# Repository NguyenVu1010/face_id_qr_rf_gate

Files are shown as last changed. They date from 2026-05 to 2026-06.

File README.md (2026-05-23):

# smart_gate (Pi 5 side)

See `docs/superpowers/specs/2026-05-22-pi-app-design.md` for design.

## Dev setup

```
python3 -m venv --system-site-packages .venv
source .venv/bin/activate
pip install -r requirements-dev.txt
pytest tests/ -q
```

## Production install

```
sudo bash scripts/install.sh
```

## Pi GPIO UART setup (one-time, before first run)

The daemon talks to ESP32 over the Pi GPIO UART (`/dev/serial0`), not USB-CDC.
Before first run:

1. Disable Pi serial console:
   ```
   sudo raspi-config
   # Interface Options → Serial Port
   #   "Login shell over serial?" → NO
   #   "Serial port hardware enabled?" → YES
   sudo reboot
   ```
2. Verify the device exists and is readable:
   ```
   ls -l /dev/serial0    # should be a symlink to ttyAMA0 or ttyS0
   ```
3. Wire 3 Dupont leads between Pi GPIO header and ESP32 DevKit:
   - Pi pin **8** (BCM14, TX0) → ESP32 **GPIO 32** (UART1 RX)
   - Pi pin **10** (BCM15, RX0) ← ESP32 **GPIO 25** (UART1 TX)
   - Pi pin **6** (GND) ↔ ESP32 GND

4. Add the daemon user to `dialout` so it can open `/dev/serial0`:
   ```
   sudo usermod -aG dialout smart-gate
   ```

## Flashing ESP32 (must stop daemon)

Firmware flashing still needs a separate USB cable from the Pi to the DevKit
USB-C/micro-USB port. `esptool.py` needs DTR/RTS auto-reset which the GPIO
UART doesn't provide.

```
sudo systemctl stop smart-gate
# Plug USB cable Pi → DevKit (data + power OK while daemon is stopped; the
# servo isn't moving and Pi USB current budget is plenty for the no-load case)
esptool.py --chip esp32 --port /dev/ttyUSB0 --baud 921600 write_flash 0x0 firmware.bin
# Unplug USB cable (or leave it for `pio device monitor` debug log)
sudo systemctl start smart-gate
```

After flashing, runtime traffic resumes over `/dev/serial0` (the GPIO UART).
The USB cable is optional while the daemon runs.

## Web admin smoke test (pre-merge)

With the daemon running and the ESP32 connected:

1. Open `http://<pi>:8080/`. Top bar shows green **LINK** pill + cap fps number + frame-age (< 1s). Stream `<img>` shows a placeholder until the camera publishes.
2. Click **⏵ Open gate** — gate opens, toast "Gate opening…". Click **⏹ Close gate** — toast "Gate closing…".
3. Click **+ Tạo user mới** → confirm dialog → enroll-result card appears with QR thumbnail + ⬇ Tải QR PNG button.
4. Trigger an authorized face match — within 2 s a new row appears at the top of Recent events.
5. Watch the gate badge cycle through `idle → opening → open → timeout_warn → closing → idle` over a 20s arc; `timeout_warn` should pulse.
6. Navigate to `/events`. Toggle the `face` filter pill — only face rows show. Clear filter, choose **denied** — only stranger rows show. Type "ali" in the user search — only alice rows. Pick "Last 7 days" period. Click `▶` on a row that has a clip — native `<dialog>` modal plays the mp4 + offers Download.
7. Navigate to `/users` — alice row visible with QR thumbnail + ⬇ download button. Counter shows "N enrolled".
8. Navigate to `/system` — four status cards green (LINK / CAP / DET / DISK), pretty-printed health JSON, two diag buttons. Click **Send ping** → modal opens with `ack_ms` integer. Click **Send cmd:status** → modal updates with the ESP32-side status payload. ESP32 log scrolls live, newest-first.
9. **Failure-mode walk:**
   - Unplug USB to ESP32. Within ~5 s:
     - Top bar LINK pill turns amber.
     - `link-banner` appears: "⚠ Link down — UART silent. Manual gate commands disabled."
     - `Open gate` → toast "Gate command failed".
     - `#sse-status` becomes "reconnecting…".
   - Replug USB. Within ~5 s: banner disappears, LINK turns green, SSE pill goes live; any ESP32 log lines emitted during the outage are replayed (uses `Last-Event-ID` resume).
10. **Pause / Clear** controls on the ESP32 log list work; capacity is bounded at 500 lines (oldest dropped).

If any step fails: `pytest tests/ -q --ignore=tests/unit/test_cli.py` should still be green; the bug is in templates/JS rather than backend.

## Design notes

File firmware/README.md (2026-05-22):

# smart_gate ESP32 firmware

Implements the firmware described in [`../docs/superpowers/specs/2026-05-22-esp32-firmware-design.md`](../docs/superpowers/specs/2026-05-22-esp32-firmware-design.md).

Talks JSON Lines over USB-CDC to a Raspberry Pi 5. Operates the gate independently of the Pi if the link is lost; RFID auth is local via NVS allowlist.

## Toolchain

- [PlatformIO](https://platformio.org/) (CLI: `pio`).
- Framework: Arduino-ESP32.
- Board: ESP32-WROOM-32 DevKit.

## Pin map (mirrors architecture spec §5)

| GPIO | Peripheral |
| --- | --- |
| 1 | UART0 TX — `pio device monitor` debug + `esptool.py` flashing only |
| 3 | UART0 RX — `pio device monitor` + `esptool.py` flashing only |
| 2 | Onboard status LED |
| 5 | RC522 CS |
| 18  | RC522 SCK |
| 19  | RC522 MISO |
| 23  | RC522 MOSI |
| 17  | RC522 RST |
| 16  | RC522 IRQ (reserved; polling mode) |
| 21  | LCD I2C SDA |
| 22  | LCD I2C SCL |
| **25**  | **UART1 TX → Pi pin 10 (BCM15, RX0)** — Pi app comm |
| **32**  | **UART1 RX ← Pi pin 8  (BCM14, TX0)** — Pi app comm |
| 27  | HC-SR04 TRIG |
| 26  | HC-SR04 ECHO (via voltage divider) |
| 13  | Servo SG90 PWM |
| 14  | Buzzer (via 2N3904 NPN) |

Runtime Pi↔ESP32 app comm uses the **3-wire GPIO UART link** (decision #26, 2026-05-23): ESP32 GPIO 32/25 ↔ Pi header pins 8/10. USB cable to the DevKit is needed only for flashing — unplugged at runtime. The Pi serial console must be disabled in `raspi-config` so `/dev/serial0` is free. LCD I2C pull-up cut required — see architecture spec §5.2.

## Build

```bash
pio run
```

First build downloads platform + libraries (~2–5 min).

## Flash

```bash
# Pi pyserial app must release /dev/ttyUSB0 first.
pio run -t upload
```

Reset is automatic via DTR/RTS on CP2102.

## Monitor

```bash
pio device monitor
```

Press Ctrl+T then Ctrl+H for the picocom-style help.

## UART protocol

See architecture spec §4. JSON Lines, 115200 baud (USB-CDC ignores baud but app config is symmetric with Pi).

Send a `ping`:

```
{"id":1,"type":"cmd","v":"ping"}
```

Expect:

```
{"type":"ack","id":1,"v":"ping","data":{"ok":true}}
```

## Acceptance tests (manual)

| # | Scenario | Expected serial output |
| --- | --- | --- |
| 1 | Power on board | One line `{"type":"evt","v":"boot","data":{"fw":"1.0.0","free_heap":N,"reset_reason":"power_on"}}` within 500 ms |
| 2 | Send `{"id":1,"type":"cmd","v":"ping"}` | `{"type":"ack","id":1,"v":"ping","data":{"ok":true}}` within 100 ms |
| 3 | Scan whitelisted card | `evt:rfid granted` with `name`; `evt:gate opening` → `evt:gate open` after 300 ms; LCD `"Welcome: <name>"`; servo physically opens |
| 4 | Pass hand through HC-SR04 beam | `evt:person_passed` with `distance_cm` and `ms`; `evt:gate closing` → `evt:gate closed` |
| 5 | Scan non-whitelisted card | `evt:rfid denied`; buzzer triple-beep; no gate motion |
| 6 | `cmd:open` then leave alone | `evt:gate opening` → `evt:gate open`; after 10 s `evt:gate timeout_warn` + buzzer warn pattern; after 5 s `evt:gate closing` → `evt:gate closed` |
| 7 | `add_uid` → `list_uids` → reboot → `list_uids` | Second `list_uids` after reboot still contains added UID |
| 8 | `remove_uid` for unknown UID | `ack` with `{"ok":false,"err":"not_found"}` |
| 9 | `cmd:config {"close_timeout_s":3}` then `cmd:open` and idle | Timeout warning fires at 3 s instead of 10 s |
| 10 | Disconnect Pi USB, scan whitelisted card | RFID auth still works end-to-end (boards standalone) |
| 11 | Send malformed JSON | `evt:log warn` with `tag:"uart"`; next valid message still processed |
| 12 | Hold whitelisted card on reader | `evt:rfid granted` fires once; identical events suppressed until card removed |

Record pass/fail in `firmware/test-log.md` (create on first acceptance run).

## Troubleshooting

- **`pio run -t upload` fails with "Resource busy"** — another process holds `/dev/ttyUSB0`. Stop the Pi app or `fuser -k /dev/ttyUSB0`.
- **No serial output at all** — check USB cable (some are charge-only), check `pio device list` for the right port name.
- **LCD shows garbage** — pull-up cut not done (architecture spec §5.2). Cut the on-backpack 4.7 kΩ pull-ups, the carrier PCB pull-ups to 3V3 take over.
- **RFID never reads** — confirm SPI wiring; the RC522 module's onboard regulator drops 3V3 if there's a short.
- **HC-SR04 always reads 0** — confirm voltage divider on ECHO (5 V → 3.3 V). Direct 5 V to GPIO 26 over time damages the input.
- **Servo jitters** — 470 µF cap on 5 V rail not installed (architecture spec §2.2).

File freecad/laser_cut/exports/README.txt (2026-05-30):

MICA GATE PILLAR — LASER CUT SPEC
=================================

Project: Smart gate pillar enclosure (Pi 4 + ESP32 + sensors)
Date:    2026-05-31
File:    mica_gate_pillar.pdf (or .svg)

VẬT LIỆU
--------
Mica acrylic trong suốt, độ dày 5 mm.
Khổ tấm: 1000 × 600 mm (1 tấm đủ).

NÉT CẮT vs NÉT KHẮC
-------------------
- Đường màu ĐỎ (RGB 255,0,0):   CẮT THỦNG
- Đường màu ĐEN (RGB 0,0,0):    KHẮC NÔNG (engrave ~0.2mm)

DANH SÁCH 8 CHI TIẾT
--------------------
1. FRONT     150 × 228 mm  (mặt trước)
2. BACK      150 × 300 mm  (mặt sau, có lỗ adapter Ø10mm)
3. LEFT      240 × 300 mm  (ngũ giác, mặt trái)
4. RIGHT     240 × 300 mm  (ngũ giác, mặt phải, có khe arm 20×130mm + cảm biến; servo dời vào trong)
5. TOP       150 × 168 mm  (mặt trên, có lỗ LCD 98×40 R4)
6. SLOPE     150 × 101.8 mm (mặt vát 45°, có khắc đánh dấu RFID)
7. BOTTOM    150 × 240 mm  (mặt đáy, có 5 khe thông gió)
8. ARM       115 × 15  mm  (cần chắn — có khắc 3 vạch sọc 20mm × 5mm — sau khi cắt sơn ĐỎ vào các vạch khắc để giả barrier sọc đỏ-trắng)

DUNG SAI
--------
±0.2 mm cho lỗ và mép.
Đường cắt cùng tấm phải canh khoảng cách >= 5mm để tránh vỡ mica.

LƯU Ý
-----
- Nét cắt trong file có độ dày 0.3mm (chỉ để hiển thị PDF); máy laser
  cắt theo đường tâm geometry, không theo độ dày stroke.
- Engrave (vùng RFID trên SLOPE và 5 vạch sọc trên ARM) chỉ cần khắc nông, không cắt thủng.

CẢM ƠN!

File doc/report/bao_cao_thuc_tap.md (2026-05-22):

# BÁO CÁO THỰC TẬP TỐT NGHIỆP

**Đề tài:** NGHIÊN CỨU, THIẾT KẾ BỘ ĐIỀU KHIỂN CỔNG THU SOÁT VÉ TỰ ĐỘNG AFC TRONG GIAO THÔNG CÔNG CỘNG

**Sinh viên thực hiện:** [HỌ TÊN SINH VIÊN]
**Mã sinh viên:** [MSV]
**Lớp:** [LỚP]
**Khóa:** [KHÓA]
**Đơn vị thực tập:** [ĐƠN VỊ THỰC TẬP]
**Giáo viên hướng dẫn:** [GVHD]
**Khoa:** Điện – Điện tử
**Trường:** Đại học Giao thông vận tải

Hà Nội, năm 2026

---

# LỜI NÓI ĐẦU

Trong xu hướng phát triển mạnh mẽ của Cách mạng công nghiệp 4.0, các hệ thống thu soát vé tự động (AFC – Automatic Fare Collection) đang trở thành thành phần không thể thiếu của hạ tầng giao thông công cộng hiện đại. Tại Việt Nam, sự ra đời của các tuyến đường sắt đô thị (metro) Hà Nội và TP. Hồ Chí Minh cùng các tuyến xe buýt nhanh (BRT) đặt ra yêu cầu cấp thiết về một thế hệ thiết bị cổng AFC tin cậy, đa dạng phương thức xác thực và có khả năng tích hợp dữ liệu về trung tâm điều hành.

Báo cáo thực tập này trình bày quá trình tìm hiểu, phân tích, thiết kế và xây dựng mô hình *Bộ điều khiển cổng thu soát vé tự động AFC* – một mô hình demo cấp prototype, áp dụng kiến trúc **dual-compute** (hai nút tính toán):

- **Raspberry Pi 5** đảm nhiệm khối thị giác máy tính: thu nhận hình ảnh từ webcam USB, nhận diện khuôn mặt, quét mã QR, lưu trữ cơ sở dữ liệu hành khách – vé và cung cấp giao diện web giám sát.
- **ESP32-WROOM-32** đảm nhiệm khối điều khiển ngoại vi thời gian thực: đọc thẻ RFID 13.56 MHz qua module RC522, điều khiển động cơ Servo SG90 đóng/mở cánh chắn, hiển thị trạng thái lên LCD 20×4, phát âm thanh báo hiệu qua buzzer, phát hiện hành khách đi qua bằng cảm biến siêu âm HC-SR04.

Hai khối tính toán giao tiếp qua **một dây cáp USB duy nhất** sử dụng USB-CDC, vận chuyển bản tin JSON Lines ở tốc độ 115200 baud. Việc tắt Wi-Fi trên ESP32 và loại bỏ MQTT giúp đơn giản hóa hệ thống, giảm bề mặt tấn công và tăng độ tin cậy cho mô hình demo.

Báo cáo trình bày đầy đủ các nội dung từ phân tích yêu cầu, lựa chọn công nghệ, thiết kế phần cứng (KiCad), thiết kế cơ khí (FreeCAD), thiết kế phần mềm (Python + Flask trên Pi, Arduino-ESP32 + FreeRTOS trên ESP32), đến kết quả thử nghiệm và hướng phát triển. Đây là tài liệu tổng kết quá trình thực tập của em tại **[ĐƠN VỊ THỰC TẬP]**, đồng thời là cơ sở để mở rộng đề tài thành đồ án tốt nghiệp.

---

# LỜI CAM KẾT

Em xin cam kết báo cáo thực tập tốt nghiệp với đề tài *“Nghiên cứu, thiết kế bộ điều khiển cổng thu soát vé tự động AFC trong giao thông công cộng”* là công trình nghiên cứu của riêng em dưới sự hướng dẫn của thầy/cô **[GVHD]**. Toàn bộ nội dung phân tích, thiết kế, sơ đồ khối, sơ đồ nguyên lý KiCad, bảng phân chân ESP32, lưu đồ thuật toán và kết quả thử nghiệm trình bày trong báo cáo đều do em thực hiện trong quá trình thực tập tại **[ĐƠN VỊ THỰC TẬP]**. Các tài liệu tham khảo được trích dẫn đầy đủ trong mục Tài liệu tham khảo.

Em xin chịu hoàn toàn trách nhiệm về nội dung báo cáo này.

Hà Nội, ngày ___ tháng ___ năm 2026
Sinh viên thực hiện
**[HỌ TÊN SINH VIÊN]**

---

# LỜI CẢM ƠN

Trong suốt quá trình thực tập tốt nghiệp và hoàn thành báo cáo, em đã nhận được rất nhiều sự giúp đỡ tận tình từ thầy cô, đồng nghiệp và bạn bè.

Trước tiên, em xin gửi lời cảm ơn chân thành đến **Ban Chủ nhiệm Khoa Điện – Điện tử**, Trường Đại học Giao thông vận tải đã tạo điều kiện thuận lợi cho em được tham gia kỳ thực tập tốt nghiệp tại doanh nghiệp.

Em xin trân trọng cảm ơn thầy/cô **[GVHD]** – giáo viên hướng dẫn – đã dành nhiều thời gian quý báu để hướng dẫn em từ khâu lựa chọn đề tài, định hình kiến trúc hệ thống, đến việc rà soát kỹ thuật trong từng phần thiết kế phần cứng và phần mềm. Những góp ý sâu sát của thầy/cô về phân bố chân ESP32, giao thức UART JSON Lines và mô hình tác vụ FreeRTOS đã giúp em tránh được nhiều lỗi tiềm ẩn.

Em cũng xin gửi lời cảm ơn đến **[ĐƠN VỊ THỰC TẬP]** đã tiếp nhận, hướng dẫn và tạo điều kiện cho em được tiếp xúc với môi trường làm việc thực tế, được sử dụng các thiết bị (Raspberry Pi 5, ESP32 DevKit DOIT V1 30-pin, module RC522, LCD I2C, Servo SG90, cảm biến HC-SR04, webcam USB) phục vụ cho việc xây dựng mô hình.

Do thời gian thực tập và năng lực còn hạn chế, báo cáo không tránh khỏi những thiếu sót. Em rất mong nhận được sự góp ý của quý thầy/cô và Hội đồng để báo cáo được hoàn thiện hơn.

Em xin chân thành cảm ơn!

Hà Nội, ngày ___ tháng ___ năm 2026
Sinh viên
**[HỌ TÊN SINH VIÊN]**

---

# MỤC LỤC

**LỜI NÓI ĐẦU** ... i
**LỜI CAM KẾT** ... ii
**LỜI CẢM ƠN** ... iii
**DANH MỤC BẢNG BIỂU** ... iv
**DANH MỤC HÌNH VẼ** ... v
**DANH MỤC CÁC CỤM TỪ VIẾT TẮT** ... vi

**CHƯƠNG 1. TỔNG QUAN VỀ HỆ THỐNG THU SOÁT VÉ TỰ ĐỘNG AFC** ... 1
1.1. Giới thiệu hệ thống AFC trong giao thông công cộng ... 1
1.2. Thiết bị cổng trong hệ thống AFC ... 4
1.3. Các công nghệ sử dụng trong thiết bị cổng AFC ... 7
1.4. Các thuật toán điều khiển phổ biến ... 10
1.5. Định hướng và lựa chọn phương án thiết kế cho đồ án ... 13
1.6. Kết luận chương 1 ... 16

**CHƯƠNG 2. THIẾT KẾ PHẦN CỨNG BỘ ĐIỀU KHIỂN CỔNG HỆ THỐNG AFC** ... 17
2.1. Sơ đồ khối tổng thể của hệ thống ... 17
2.2. Lựa chọn thiết bị và linh kiện phần cứng ... 20
2.3. Thiết kế chi tiết phần cứng bộ điều khiển cổng ... 26
2.4. Thiết kế PCB mạch điều khiển và mô hình thiết bị cổng ... 32
2.5. Kết luận chương 2 ... 35

**CHƯƠNG 3. THIẾT KẾ PHẦN MỀM ĐIỀU KHIỂN VÀ XỬ LÝ DỮ LIỆU AFC** ... 36
3.1. Các yêu cầu của phần mềm điều khiển và xử lý dữ liệu ... 36
3.2. Thiết kế cơ sở dữ liệu ... 39
3.3. Thiết kế thuật toán điều khiển ... 43
3.4. Thiết kế giao diện giám sát ... 53
3.5. Kết luận chương 3 ... 56

**CHƯƠNG 4. CÁC KẾT QUẢ THỬ NGHIỆM VÀ ĐÁNH GIÁ** ... 57
4.1. Các sản phẩm của đồ án ... 57
4.2. Các kết quả thử nghiệm sản phẩm ... 60
4.3. Đánh giá sản phẩm ... 65
4.4. Kết luận chương 4 ... 67

**KẾT LUẬN CHUNG** ... 68
**HƯỚNG PHÁT TRIỂN CỦA ĐỀ TÀI** ... 69
**TÀI LIỆU THAM KHẢO** ... 71
**PHỤ LỤC** ... 73

---

# DANH MỤC BẢNG BIỂU

| Bảng | Nội dung |
|---|---|
| Bảng 1.1 | So sánh các loại cổng AFC phổ biến |
| Bảng 1.2 | So sánh các phương thức xác thực vé trong AFC |
| Bảng 1.3 | So sánh các phương án thiết kế đã cân nhắc |
| Bảng 2.1 | Tóm tắt các linh kiện chính của hệ thống |
| Bảng 2.2 | Thông số kỹ thuật Raspberry Pi 5 |
| Bảng 2.3 | Thông số kỹ thuật ESP32-WROOM-32 (DOIT V1 30-pin) |
| Bảng 2.4 | Thông số kỹ thuật module RFID RC522 |
| Bảng 2.5 | Thông số kỹ thuật Servo SG90 |
| Bảng 2.6 | Thông số kỹ thuật cảm biến siêu âm HC-SR04 |
| Bảng 2.7 | Thông số kỹ thuật LCD 20×4 (PCF8574 I2C backpack) |
| Bảng 2.8 | Phân bố chân (Pin assignment) trên ESP32 DOIT V1 30-pin |
| Bảng 2.9 | Ước tính dòng điện tiêu thụ trên các đường nguồn |
| Bảng 3.1 | Danh sách 8 luồng (thread) trong tiến trình Pi 5 |
| Bảng 3.2 | Mô hình tác vụ FreeRTOS trên ESP32 |
| Bảng 3.3 | Bộ động từ lệnh (command verbs) trong giao thức UART |
| Bảng 3.4 | Bộ động từ sự kiện (event verbs) trong giao thức UART |
| Bảng 3.5 | Tổng hợp 20 thuật toán/cấu trúc dữ liệu chính |
| Bảng 4.1 | Kết quả đo độ trễ và tốc độ khung hình nhận diện khuôn mặt |
| Bảng 4.2 | Kết quả đo thời gian đóng/mở cánh chắn |
| Bảng 4.3 | Kết quả 12 kịch bản nghiệm thu firmware ESP32 |
| Bảng 4.4 | Tóm tắt mức đáp ứng yêu cầu thiết kế R1–R14 |

---

# DANH MỤC HÌNH VẼ

| Hình | Nội dung |
|---|---|
| Hình 1.1 | Mô hình tổng quan hệ thống AFC trong giao thông công cộng |
| Hình 1.2 | Quy trình xử lý vé trong hệ thống AFC |
| Hình 1.3 | Các loại cổng AFC: tripod, flap, swing, sliding |
| Hình 1.4 | Quy trình xác thực đa phương thức (Face / QR / RFID) |
| Hình 2.1 | Sơ đồ khối tổng quát hệ thống Smart Gate dual-compute |
| Hình 2.2 | Bo mạch Raspberry Pi 5 và sơ đồ chân |
| Hình 2.3 | Module ESP32 DevKit DOIT V1 30-pin |
| Hình 2.4 | Module RFID RC522 và thẻ Mifare 13.56 MHz |
| Hình 2.5 | Cấu tạo Servo SG90 |
| Hình 2.6 | Nguyên lý hoạt động cảm biến siêu âm HC-SR04 |
| Hình 2.7 | LCD 20×4 với PCF8574 backpack I2C |
| Hình 2.8 | Sơ đồ nguyên lý mạch carrier ESP32 (KiCad) |
| Hình 2.9 | Sơ đồ mạch in (PCB) 2D mặt trước/mặt sau |
| Hình 2.10 | Mô hình 3D PCB carrier |
| Hình 2.11 | Bản vẽ cơ khí khung cổng (FreeCAD) |
| Hình 2.12 | Mô hình lắp ráp thực tế |
| Hình 3.1 | Kiến trúc phần mềm trên Pi 5 (8 luồng) |
| Hình 3.2 | FrameHub fan-out pipeline |
| Hình 3.3 | Sơ đồ quan hệ thực thể (ER) cơ sở dữ liệu SQLite |
| Hình 3.4 | Lưu đồ thuật toán điều khiển tổng thể |
| Hình 3.5 | Lưu đồ thuật toán xử lý RFID |
| Hình 3.6 | Lưu đồ thuật toán quét mã QR |
| Hình 3.7 | Lưu đồ thuật toán nhận dạng khuôn mặt |
| Hình 3.8 | Máy trạng thái cổng (Gate FSM) trên ESP32 |
| Hình 3.9 | Lưu đồ thuật toán chống gian lận |
| Hình 3.10 | Sơ đồ chức năng giao diện giám sát Flask |
| Hình 3.11 | Bố cục dashboard giám sát |
| Hình 4.1 | Hệ thống lắp ráp hoàn thiện |
| Hình 4.2 | Giao diện web admin (dashboard) |
| Hình 4.3 | Sơ đồ kết nối kiểm tra trên bench |

---

# DANH MỤC CÁC CỤM TỪ VIẾT TẮT

| STT | Từ viết tắt | Tiếng Anh | Nghĩa tiếng Việt |
|---|---|---|---|
| 1 | AFC | Automatic Fare Collection | Hệ thống thu vé tự động |
| 2 | AI | Artificial Intelligence | Trí tuệ nhân tạo |
| 3 | API | Application Programming Interface | Giao diện lập trình ứng dụng |
| 4 | BLE | Bluetooth Low Energy | Bluetooth năng lượng thấp |
| 5 | BRT | Bus Rapid Transit | Xe buýt nhanh khối lượng lớn |
| 6 | CCH | Central Clearing House | Trung tâm đối soát giao dịch |
| 7 | CDC | Communications Device Class | Lớp thiết bị truyền thông (USB) |
| 8 | CPU | Central Processing Unit | Bộ xử lý trung tâm |
| 9 | CSI | Camera Serial Interface | Giao tiếp camera nối tiếp |
| 10 | FSM | Finite State Machine | Máy trạng thái hữu hạn |
| 11 | GPIO | General Purpose Input Output | Cổng vào/ra đa năng |
| 12 | HLS | HTTP Live Streaming | Truyền video trực tuyến qua HTTP |
| 13 | I2C | Inter-Integrated Circuit | Bus truyền nối tiếp hai dây |
| 14 | IoT | Internet of Things | Vạn vật kết nối |
| 15 | JSON | JavaScript Object Notation | Định dạng đối tượng JavaScript |
| 16 | LCD | Liquid Crystal Display | Màn hình tinh thể lỏng |
| 17 | LDO | Low-Dropout Regulator | IC ổn áp tuyến tính sụt áp thấp |
| 18 | LED | Light Emitting Diode | Đi-ốt phát quang |
| 19 | LEDC | LED Controller | Bộ điều khiển LED (PWM trên ESP32) |
| 20 | MJPEG | Motion JPEG | Định dạng video chuỗi ảnh JPEG |
| 21 | MQTT | Message Queuing Telemetry Transport | Giao thức truyền tin nhẹ cho IoT |
| 22 | NFC | Near Field Communication | Truyền thông tầm gần |
| 23 | NVS | Non-Volatile Storage | Bộ nhớ không mất khi mất điện |
| 24 | OTA | Over The Air | Cập nhật từ xa qua không dây |
| 25 | PCB | Printed Circuit Board | Bảng mạch in |
| 26 | PWM | Pulse Width Modulation | Điều chế độ rộng xung |
| 27 | QR | Quick Response | Mã phản hồi nhanh |
| 28 | RAM | Random Access Memory | Bộ nhớ truy cập ngẫu nhiên |
| 29 | RFID | Radio Frequency Identification | Nhận dạng tần số vô tuyến |
| 30 | RTOS | Real-Time Operating System | Hệ điều hành thời gian thực |
| 31 | SBC | Single Board Computer | Máy tính nhúng một bo mạch |
| 32 | SoC | System on Chip | Hệ thống trên một chip |
| 33 | SPI | Serial Peripheral Interface | Bus truyền nối tiếp ngoại vi |
| 34 | SQL | Structured Query Language | Ngôn ngữ truy vấn cơ sở dữ liệu |
| 35 | TTL | Transistor-Transistor Logic | Logic mức điện áp transistor |
| 36 | TVM | Ticket Vending Machine | Máy bán vé tự động |
| 37 | UART | Universal Asynchronous Receiver-Transmitter | Truyền thông nối tiếp không đồng bộ |
| 38 | USB | Universal Serial Bus | Bus nối tiếp đa dụng |
| 39 | UVC | USB Video Class | Lớp video chuẩn USB |
| 40 | WAL | Write-Ahead Logging | Chế độ ghi-nhật-ký-trước (SQLite) |

---

# CHƯƠNG 1. TỔNG QUAN VỀ HỆ THỐNG THU SOÁT VÉ TỰ ĐỘNG AFC

## 1.1. Giới thiệu hệ thống AFC trong giao thông công cộng

### 1.1.1. Khái niệm hệ thống AFC

AFC (Automatic Fare Collection – Hệ thống thu vé tự động) là tập hợp các thiết bị, phần mềm và quy trình cho phép thu phí dịch vụ giao thông công cộng (đường sắt đô thị, xe buýt nhanh, phà, bãi gửi xe…) một cách tự động, không cần nhân viên bán/xé vé thủ công. Hệ thống AFC hiện đại đảm nhiệm toàn bộ vòng đời của một giao dịch vé: phát hành – nạp tiền – soát vé tại cổng – ghi nhận giao dịch – đối soát giữa các bên khai thác.

Mục tiêu cốt lõi của AFC bao gồm: rút ngắn thời gian soát vé (target < 1 s/hành khách), giảm chi phí nhân lực, hạn chế gian lận, hỗ trợ đa dạng phương thức thanh toán (thẻ không tiếp xúc, điện thoại NFC, mã QR, sinh trắc khuôn mặt), và cung cấp số liệu thống kê chính xác cho cơ quan quản lý.

### 1.1.2. Vai trò của AFC trong giao thông công cộng

Trong bối cảnh đô thị hóa nhanh tại Hà Nội, TP. Hồ Chí Minh và các thành phố lớn, AFC đóng vai trò không thể thay thế:

1. **Tăng năng lực thông qua (throughput)** của các nút đầu vào trạm metro/BRT: cổng AFC hiện đại đạt 40–60 hành khách/phút, gấp 3–5 lần soát thủ công.
2. **Giảm chi phí vận hành** dài hạn: thay thế hàng chục nhân viên bán/soát vé mỗi ngày bằng một bộ vài chục cổng tự động + bộ phận bảo trì.
3. **Chống thất thoát doanh thu** nhờ ghi nhật ký giao dịch chi tiết, có khả năng đối soát giữa nhà điều hành tuyến và bên thanh toán.
4. **Tạo dữ liệu phục vụ quy hoạch:** dữ liệu thẻ định danh (anonymized) giúp phân tích luồng hành khách, phục vụ tối ưu tuyến và lịch chạy tàu.
5. **Mở đường tích hợp đa phương tiện:** một thẻ duy nhất dùng được cho metro + BRT + bus + bãi gửi xe – mô hình "Mobility as a Service".

Tại Hà Nội, *Quyết định 3680/QĐ-UBND năm 2024* ban hành tiêu chuẩn kỹ thuật cho hệ thống AFC đã định hướng rõ về giao thức trao đổi thẻ (ISO/IEC 14443), độ trễ tối đa khi xác thực, mức ưu tiên giữa các loại thẻ và yêu cầu lưu nhật ký kiểm toán.

### 1.1.3. Kiến trúc hệ thống AFC

Hình 1.1 mô tả kiến trúc tổng quan của một hệ thống AFC hoàn chỉnh, gồm 4 tầng chính:

```
┌──────────── Tầng 1: Thiết bị tại trạm (Station Edge) ──────────┐
│  • Cổng soát vé (Fare Gate / Turnstile)                         │
│  • Máy bán vé tự động (TVM – Ticket Vending Machine)            │
│  • Máy nạp tiền (Add-Value Machine)                             │
│  • Thiết bị POS cầm tay (Hand-held Validator)                   │
└─────────────────────────────┬──────────────────────────────────┘
                              │ Mạng LAN trạm
┌─────────────────────────────┴─────────────────────────────────┐
│       Tầng 2: Trung tâm điều hành trạm (Station Control)       │
│  • Máy chủ kiểm soát truy cập (Station Controller)             │
│  • Cơ sở dữ liệu local cache vé hợp lệ                          │
└─────────────────────────────┬─────────────────────────────────┘
                              │ Mạng WAN
┌─────────────────────────────┴─────────────────────────────────┐
│      Tầng 3: Trung tâm điều hành tuyến (Line Control)          │
│  • Quản lý cấu hình tuyến, đồng bộ giá vé                       │
│  • Tổng hợp giao dịch trong ngày                                │
└─────────────────────────────┬─────────────────────────────────┘
                              │
┌─────────────────────────────┴─────────────────────────────────┐
│   Tầng 4: Trung tâm đối soát giao dịch CCH (Central Clearing) │
│  • Đối soát doanh thu giữa các nhà khai thác                   │
│  • Lưu trữ dài hạn cho kiểm toán (≥ 5 năm)                      │
│  • Cấp phép thẻ định danh, quản lý blacklist                    │
└─────────────────────────────────────────────────────────────────┘
```

**Hình 1.1.** *Mô hình tổng quan hệ thống AFC trong giao thông công cộng.*

Đề tài thực tập tập trung vào **Tầng 1**, cụ thể là *thiết bị cổng soát vé*. Các tầng 2–4 chỉ được đề cập ở mức bối cảnh.

### 1.1.4. Quy trình xử lý vé trong hệ thống AFC

Mỗi giao dịch vé tại cổng AFC tuần tự qua các bước:

1. **Phát hiện hành khách tiếp cận:** cảm biến (hồng ngoại, siêu âm hoặc thị giác máy tính) phát hiện hành khách đến gần đầu đọc.
2. **Áp vé / quét QR / nhận diện khuôn mặt:** hành khách thực hiện hành động xác thực phù hợp với loại vé sở hữu.
3. **Đọc dữ liệu thẻ/QR:** thiết bị đầu đọc gửi dữ liệu (UID thẻ, payload QR, embedding khuôn mặt) đến bộ điều khiển cổng.
4. **Tra cứu local cache:** bộ điều khiển kiểm tra trong cache cục bộ xem vé có hợp lệ, đủ số dư, chưa bị blacklist không.
5. **Quyết định cho qua hay từ chối:** nếu hợp lệ → kích cánh chắn mở; nếu không → hiển thị lý do từ chối (hết hạn, không đủ tiền, thẻ giả…) trên LCD.
6. **Ghi nhật ký giao dịch (transaction log):** bao gồm thời gian, mã thẻ, kết quả, mã trạm, số tiền trừ (nếu có).
7. **Theo dõi hành khách đi qua:** cảm biến vùng trong/ngoài cổng xác nhận hành khách đã thực sự đi qua – đóng cánh chắn ngay sau đó.
8. **Đồng bộ giao dịch về Tầng 2:** định kỳ hoặc real-time, đẩy log giao dịch lên Station Controller, sau đó về CCH.

**Hình 1.2.** *Quy trình xử lý vé trong hệ thống AFC.*

Tổng thời gian từ bước 2 đến bước 6 thường được kỳ vọng ≤ 1 giây để duy trì throughput. Đề tài Smart Gate triển khai một subset đầy đủ của quy trình này (bước 1–7), bỏ bước 8 vì là mô hình demo độc lập.

## 1.2. Thiết bị cổng trong hệ thống AFC

### 1.2.1. Cấu tạo thiết bị cổng AFC

Một thiết bị cổng AFC tiêu chuẩn gồm 4 cụm chính:

- **Cụm cơ khí (mechanical):** khung kim loại, cánh chắn (flap/arm/tripod), động cơ truyền động (Servo/DC motor + encoder), bộ truyền cơ khí (bánh răng hoặc tay đòn).
- **Cụm cảm biến (sensing):** mảng hồng ngoại / siêu âm để phát hiện hành khách vùng "trước-cổng", "trong-cổng" và "sau-cổng"; cảm biến vật cản chống kẹp người.
- **Cụm đầu đọc (reader):** RFID/NFC 13.56 MHz, camera QR, camera khuôn mặt, đầu đọc thẻ ngân hàng tiếp xúc/không tiếp xúc.
- **Cụm điều khiển và hiển thị (control & HMI):** bộ điều khiển trung tâm (PLC/MCU/SBC), LCD hiển thị trạng thái, đèn LED chỉ thị màu xanh-đỏ-vàng, loa hoặc buzzer thông báo.

Tại các tuyến đường sắt đô thị Hà Nội (Cát Linh – Hà Đông, Nhổn – ga Hà Nội), TP. Hồ Chí Minh (Bến Thành – Suối Tiên) và một số tuyến BRT, các nhà cung cấp thiết bị (Thales, Indra, Samsung SDS, Cubic Transportation, GMV, Sancosis…) đang được sử dụng. Đề tài tham khảo nguyên lý chung từ các giải pháp này, không đề cập sản phẩm thương mại cụ thể.

### 1.2.2. Nguyên lý hoạt động

Khi không có hành khách, cánh chắn ở trạng thái OPEN (mặc định cho phép luồng người đi qua – sliding door) hoặc CLOSED (mặc định chặn – flap/tripod). Hai chế độ này được gọi là *normally open* và *normally closed*. Đề tài Smart Gate dùng *normally closed* để bảo đảm an toàn (nếu mất điện thì cổng giữ trạng thái đóng, hành khách không lọt vào miễn phí).

Khi phát hiện hành khách tiếp cận:
- Đầu đọc thẻ/QR/khuôn mặt liên tục quét.
- Nếu xác thực thành công → bộ điều khiển trung tâm gửi lệnh mở cánh chắn → cảm biến chờ hành khách đi qua → đóng cánh chắn ngay.
- Nếu xác thực thất bại → đèn đỏ + thông báo trên LCD + buzzer cảnh báo; cánh chắn giữ nguyên.

Các tình huống an toàn:
- **Hành khách kẹt vào cổng:** cảm biến vùng-trong phát hiện vật cản → cánh chắn không đóng cho đến khi vùng trong sạch.
- **Mở cổng nhưng không đi qua:** sau timeout (5–10 s), cổng tự đóng + cảnh báo.
- **Đi qua không xác thực (tailgate / piggyback):** cảm biến vùng-trong + camera đếm người phát hiện có nhiều hơn 1 người đi qua sau 1 lần mở → trigger alarm.

### 1.2.3. Phân loại các thiết bị cổng

Bảng 1.1 so sánh 4 loại cổng AFC phổ biến trên thị trường (Hình 1.3):

**Bảng 1.1. So sánh các loại cổng AFC phổ biến**

| Loại | Mô tả | Throughput | Ưu điểm | Nhược điểm | Ứng dụng điển hình |
|---|---|---|---|---|---|
| Tripod turnstile | 3 thanh quay 120° | 20–30 ng/ph | Rẻ, đơn giản, bền | Khó qua cho người khuyết tật, hành lý cồng kềnh | Phòng tập, sự kiện, nhà ga nhỏ |
| Flap barrier | 2 cánh nhựa/kính lật ngang | 40–60 ng/ph | Nhanh, sang trọng | Phức tạp, đắt | Metro Hà Nội, TP HCM, văn phòng cao cấp |
| Swing barrier | Cánh quay ngang 90° | 30–40 ng/ph | Cho qua hành lý lớn, xe đẩy | Chiếm diện tích lớn | Sân bay, bệnh viện |
| Sliding barrier | Cánh trượt ngang | 40–50 ng/ph | Đẹp, đóng kín | Cơ khí phức tạp | Khu vực VIP |

**Hình 1.3.** *Các loại cổng AFC: tripod, flap, swing, sliding.*

Đề tài Smart Gate chọn mô hình **barrier-arm (cánh chắn quay 90°)** – tương tự swing barrier nhưng đơn giản hơn (chỉ một cánh, dùng Servo nhỏ). Quyết định này điều chỉnh từ yêu cầu ban đầu trong file `requirement.txt` (đề cập "cửa trượt") bởi vì cánh chắn quay đơn giản về cơ khí, dễ thi công cấp prototype với MDF/acrylic.

### 1.2.4. Yêu cầu kỹ thuật của thiết bị cổng

Một thiết bị cổng AFC để vận hành thực tế cần đáp ứng:

| Yêu cầu | Định lượng |
|---|---|
| Throughput | ≥ 30 hành khách/phút/cổng |
| Thời gian xác thực vé | ≤ 1 s |
| Thời gian mở cánh chắn | ≤ 0.5 s |
| Độ tin cậy (MTBF) | ≥ 50.000 giờ |
| Nhiệt độ làm việc | 0 °C – 50 °C |
| Cấp bảo vệ IP | IP44 (chống bụi và nước bắn) |
| Điện áp cung cấp | 100–240 VAC, 50/60 Hz |
| Tiêu thụ điện | ≤ 60 W trạng thái nghỉ, ≤ 250 W khi đóng/mở |
| Phương thức xác thực | Tối thiểu 2 (thẻ + 1 phương thức khác) |
| Nhật ký giao dịch | Lưu local ≥ 7 ngày, đồng bộ về CCH |
| Tuân thủ tiêu chuẩn | ISO/IEC 14443 (thẻ), EMV (thẻ ngân hàng), ISO 9001 (quản lý chất lượng) |

Đề tài thực tập **không** đặt mục tiêu đạt mức công nghiệp các tiêu chí trên (MTBF, IP44, EMV…) – mô hình demo chỉ mô phỏng nguyên lý.

## 1.3. Các công nghệ sử dụng trong thiết bị cổng AFC

Phần này phân tích các nhóm công nghệ điển hình ứng dụng cho cổng AFC, có liên hệ trực tiếp đến lựa chọn thiết kế của đề tài.

### 1.3.1. Công nghệ RFID/NFC

RFID 13.56 MHz (chuẩn ISO/IEC 14443A) là công nghệ thẻ không tiếp xúc phổ biến nhất trong AFC nhờ:
- Tốc độ giao dịch nhanh (≤ 300 ms).
- Khoảng đọc 3–10 cm phù hợp tự nhiên.
- Hỗ trợ giao dịch mã hóa (Mifare DESFire EV2, EV3).
- Tương thích với hầu hết điện thoại NFC.

Đề tài dùng module RC522 (chip MFRC522 của NXP) đọc thẻ Mifare Classic 1K – là dòng thẻ trắng phổ thông dùng cho mô hình demo.

### 1.3.2. Công nghệ QR Code

Mã QR (Quick Response) cho phép xác thực vé thông qua:
- Vé giấy in QR (single-use, time-limited).
- Vé điện tử hiển thị trên màn hình điện thoại.
- Thẻ thành viên có QR tĩnh.

Ưu điểm của QR so với RFID: chi phí gần như bằng 0 (in giấy), không cần thẻ vật lý chuyên dụng, hỗ trợ bởi mọi smartphone. Nhược điểm: dễ bị copy (cần ký số HMAC + TTL), yêu cầu camera + bộ giải mã.

Đề tài dùng thư viện pyzbar (wrapper Python của libzbar) để giải mã QR trên Pi 5.

### 1.3.3. Công nghệ sinh trắc khuôn mặt

Sinh trắc khuôn mặt (face biometrics) là xu hướng AFC thế hệ mới – đã triển khai tại Trung Quốc (metro Bắc Kinh, Thượng Hải) và một số tuyến châu Âu. Ưu điểm: không cần thẻ vật lý, không cần mang theo điện thoại; nhược điểm: yêu cầu camera chất lượng tốt, dữ liệu sinh trắc nhạy cảm về quyền riêng tư.

Đề tài dùng MediaPipe Face Detection (Google) cho khoanh khuôn mặt và `face_recognition` (wrapper Python của dlib) cho trích xuất embedding 128 chiều.

### 1.3.4. Động cơ và cơ cấu truyền động

Cánh chắn trên cổng AFC công nghiệp thường dùng:
- **Servo motor công suất lớn** (10–20 kg·cm, 24 VDC) với encoder + driver kín kẽ.
- **Stepper motor** (NEMA17/23) cho định vị chính xác.
- **DC motor + bộ truyền giảm tốc** kết hợp encoder quang.

Đề tài chọn **Servo SG90** (1.8 kg·cm) – đủ cho cánh chắn balsa/acrylic 80 mm cấp prototype. Servo SG90 thông dụng, giá rẻ (~30.000 đ), cấp nguồn 5 V, điều khiển bằng PWM 50 Hz.

### 1.3.5. Cảm biến phát hiện hành khách

Các phương án phổ biến:
- **Hồng ngoại khe chắn (through-beam IR):** đơn giản, rẻ; nhưng dễ nhiễu ánh sáng mạnh.
- **Cảm biến siêu âm:** đo khoảng cách thực; ít bị nhiễu ánh sáng; phù hợp môi trường có bụi.
- **Cảm biến laser ToF (Time-of-Flight):** chính xác, đắt.
- **Camera + thị giác máy tính:** đếm người, phát hiện tailgate.

Đề tài chọn **HC-SR04** (siêu âm) thay cho IR như yêu cầu ban đầu trong `requirement.txt`, lý do:
- HC-SR04 trả về khoảng cách thực (cm) thay vì chỉ "có/không".
- Ít bị nhiễu bởi ánh sáng mặt trời và đèn huỳnh quang công suất lớn.
- Cùng giá thành (~30.000 đ), giao tiếp đơn giản (TRIG + ECHO).

### 1.3.6. Bộ điều khiển trung tâm

Các phương án có thể dùng cho bộ điều khiển cổng:
- **PLC công nghiệp** (Siemens, Mitsubishi, Schneider): độ tin cậy cao, đắt.
- **SBC (Linux)** như Raspberry Pi, BeagleBone: linh hoạt, mạnh, có thể chạy AI.
- **MCU** (ESP32, STM32, NXP Kinetis): real-time tốt, tiêu thụ thấp.
- **Kiến trúc kết hợp:** SBC cho vision + MCU cho real-time control.

Đề tài chọn **kiến trúc kết hợp Pi 5 + ESP32** cho mô hình demo – đây là điểm khác biệt chính so với các đồ án sinh viên thường gặp (thường dùng đơn lẻ Pi hoặc đơn lẻ ESP32).

## 1.4. Các thuật toán điều khiển phổ biến

### 1.4.1. Thuật toán xử lý RFID

Quy trình chuẩn cho cổng AFC RFID-only:

```
[Polling RC522 mỗi 50 ms]
    │
    ▼
[IsNewCardPresent()? ──── Không ──▶ tiếp tục polling]
    │ Có
    ▼
[ReadCardSerial() → UID]
    │
    ▼
[Lookup local cache → status]
    │
    ├── Hợp lệ ──▶ [Trừ tiền (nếu cần) → Mở cổng → Ghi log]
    │
    ├── Hết hạn ──▶ [LCD "Expired" + đèn đỏ + buzzer]
    │
    ├── Hết tiền ──▶ [LCD "Insufficient" + đèn đỏ + buzzer]
    │
    └── Không tồn tại / Blacklist ──▶ [LCD "Invalid" + alarm]
    │
    ▼
[HaltA() + StopCrypto1()  ← để thẻ không bị đọc trùng]
    │
    ▼
[Tiếp tục polling]
```

Đề tài đơn giản hóa: chỉ kiểm tra UID có trong NVS allowlist không (không có khái niệm số dư).

### 1.4.2. Thuật toán đọc QR

```
[Capture khung BGR từ webcam]
    │
    ▼
[pyzbar.decode(bgr)]
    │
    ├── Không có QR ──▶ tiếp tục
    │
    ▼ Có
[token = symbol.data.decode('utf-8')]
    │
    ▼
[Verify HMAC (production) hoặc lookup DB (demo)]
    │
    ├── Hợp lệ ──▶ [Mở cổng → Ghi log]
    │
    └── Không hợp lệ ──▶ [Lặng lẽ bỏ qua hoặc ghi attempt]
```

### 1.4.3. Thuật toán nhận dạng khuôn mặt

Một pipeline điển hình:

```
[Capture frame RGB]
    │
    ▼
[Face Detection (MediaPipe / MTCNN / RetinaFace) → bbox]
    │
    ▼
[Crop + align + normalize]
    │
    ▼
[Face Embedding (FaceNet / ArcFace / dlib) → vector 128–512 dim]
    │
    ▼
[Compare với DB embedding bằng cosine similarity hoặc Euclidean distance]
    │
    ├── distance < threshold ──▶ [Grant]
    │
    └── distance ≥ threshold ──▶ [Stranger]
```

Anti-spoofing là bước phụ trợ quan trọng để tránh tấn công bằng ảnh in, video phát lại hoặc mặt nạ 3D. Các kỹ thuật: liveness detection (chớp mắt, quay đầu), texture analysis (moiré pattern), depth sensing (camera stereo).

### 1.4.4. Thuật toán điều khiển cổng

Cổng AFC điển hình dùng máy trạng thái hữu hạn (FSM) gồm 5 trạng thái:

- `IDLE`: cổng đóng, chờ xác thực.
- `OPENING`: cánh chắn đang mở (~300 ms).
- `OPEN_WAIT`: cổng mở, chờ hành khách đi qua (timeout 10 s).
- `TIMEOUT_WARN`: hết timeout chưa thấy đi qua → buzzer cảnh báo (5 s).
- `CLOSING`: cánh chắn đang đóng (~300 ms).

Đề tài triển khai chính xác FSM này trong firmware ESP32 (mục 3.3 và Hình 3.8).

### 1.4.5. Thuật toán chống gian lận

Các pattern gian lận thường gặp tại cổng AFC:
- **Tailgating / piggyback:** 2 người đi sau 1 lần xác thực.
- **Vault jumping:** nhảy qua cánh chắn.
- **Card sharing:** truyền thẻ qua cổng cho người sau.
- **Photo attack:** dùng ảnh in mặt người dùng.

Các thuật toán chống gian lận:
- **Counting beam:** đếm số lần cảm biến chuyển trạng thái – nếu 2 lần "có vật cản" sau 1 lần mở thì cảnh báo.
- **Camera person-counter:** YOLO + tracking đếm số lượng người đi qua.
- **Anti-spoofing biometric:** liveness check.
- **Time-based limit:** thẻ A không được dùng lại trong cùng trạm < N giây.

Đề tài Smart Gate **không** triển khai chống gian lận đầy đủ – đây là một trong các hướng phát triển (mục Hướng phát triển).

## 1.5. Định hướng và lựa chọn phương án thiết kế cho đồ án

### 1.5.1. Mục tiêu nghiên cứu

Mục tiêu của đợt thực tập tốt nghiệp:

1. **Nắm vững kiến trúc dual-compute** trong hệ thống nhúng AFC: hiểu khi nào dùng SBC, khi nào dùng MCU, làm sao để hai bên giao tiếp ổn định.
2. **Thực hành thiết kế đầu-cuối** từ spec đến triển khai: viết tài liệu thiết kế, vẽ sơ đồ khối, phân chân ESP32, vẽ schematic KiCad, mô hình hóa 3D bằng FreeCAD, viết firmware ESP32 (PlatformIO + FreeRTOS), viết ứng dụng Pi (Python + Flask).
3. **Áp dụng các thư viện thị giác máy tính** OpenCV, MediaPipe, face_recognition, pyzbar trong môi trường thực.
4. **Thiết kế giao thức UART** mức ứng dụng: khung tin JSON Lines, bộ động từ lệnh/sự kiện, cơ chế ACK + heartbeat.
5. **Vận dụng FreeRTOS** trên ESP32: tạo task, queue, timer, watchdog.
6. **Quản lý cơ sở dữ liệu** SQLite cho user, face encoding, QR token, transaction log.
7. **Xây dựng giao diện web** giám sát với Flask + HTMX + Pico.css, đủ tối thiểu để demo.
8. **Đánh giá định lượng** hệ thống: độ trễ nhận diện, FPS, thời gian đóng/mở cánh chắn, độ ổn định liên kết UART.

### 1.5.2. Phạm vi đề tài

Phạm vi **bao gồm**:
- Mô hình demo bàn cấp prototype, kích thước ~200 × 100 × 100 mm.
- Một cổng đơn (single gate) với một cánh chắn quay 90°.
- Xác thực 3 phương thức: Face + QR + RFID.
- Cảm biến hành khách đi qua: HC-SR04 siêu âm.
- Giao diện giám sát local: Flask trên Pi 5, truy cập LAN.
- CSDL local: SQLite trên Pi 5.

Phạm vi **không bao gồm**:
- Tích hợp với hệ thống AFC thực tại nhà ga.
- Cloud / multi-gate federation / MQTT broker.
- Anti-spoofing khuôn mặt.
- Authentication trên giao diện web admin.
- Tuân thủ tiêu chuẩn công nghiệp (IP44, EMV, ISO 9001).
- Counting tailgate qua camera.
- Encrypted ticketing (Mifare DESFire EV2/EV3).

### 1.5.3. So sánh các phương án thiết kế

Đề tài đã trải qua 4 phương án thiết kế trước khi chốt phương án cuối:

**Bảng 1.3. So sánh các phương án thiết kế đã cân nhắc**

| Phương án | Mô tả | Ưu điểm | Nhược điểm | Quyết định |
|---|---|---|---|---|
| 1 | ESP32-CAM xử lý tất cả | Đơn giản, 1 board | CPU không đủ chạy face_recognition; PSRAM nhỏ | **Loại** |
| 2 | Pi 5 xử lý tất cả | Mạnh, full Linux | Thiếu PWM phần cứng cho Servo; SPI real-time không an toàn; nếu Pi crash, cánh chắn "đứng" | **Loại** |
| 3 | Pi 5 + ESP32 nối UART rời + Wi-Fi backup | Có dự phòng Wi-Fi | Nhiều đầu nối; phụ thuộc hạ tầng mạng; phức tạp | **Loại** |
| 4 | Pi 5 + ESP32 nối qua 1 dây USB-CDC, NVS allowlist độc lập | Đơn giản nhất; ESP32 hoạt động độc lập | – | **Chọn** |

### 1.5.4. Yêu cầu thiết kế

Bảng yêu cầu R1–R14 (chi tiết kiểm tra ở Chương 4):

| # | Yêu cầu | Tiêu chí kiểm tra |
|---|---|---|
| R1 | Xác thực bằng khuôn mặt | Đúng người trong DB → mở cổng < 2 s |
| R2 | Xác thực bằng QR | Mã hợp lệ → mở cổng < 1 s |
| R3 | Xác thực bằng RFID | Thẻ trong allowlist → mở cổng < 0.5 s |
| R4 | Cánh chắn mở/đóng đúng góc | Mở 100°, đóng 10°, sai số ≤ 5° |
| R5 | Phát hiện hành khách đã qua | HC-SR04 báo trong < 1 s |
| R6 | Cảnh báo nếu không đi qua | Sau 10 s OPEN_WAIT, buzzer warn |
| R7 | Cưỡng bức đóng nếu cảnh báo | Sau 5 s warn, tự đóng |
| R8 | LCD hiển thị tên người dùng | Đúng `"Welcome: <tên>"` khi mở cổng |
| R9 | Ghi sự kiện vào SQLite | Mỗi xác thực → 1 dòng `events`, có `clip_path` |
| R10 | Web admin xem trực tiếp | LAN truy cập `http://<pi>:8080`, thấy MJPEG |
| R11 | Standalone resilience | Rút USB → ESP32 vẫn xác thực RFID + mở/đóng được |
| R12 | Khởi động lại tự động | systemd restart-on-failure |
| R13 | Thi công gọn | Hộp 200 × 100 × 40 mm chứa Pi + carrier ESP32 |
| R14 | Đủ tài liệu | spec, schematic, BOM, README, báo cáo |

## 1.6. Kết luận chương 1

Chương 1 đã giới thiệu tổng quan về hệ thống thu soát vé tự động AFC, vai trò của AFC trong giao thông công cộng và quy trình xử lý vé tại cổng. Các loại thiết bị cổng (tripod, flap, swing, sliding) và các công nghệ cốt lõi (RFID/NFC, QR, sinh trắc khuôn mặt, động cơ Servo, cảm biến) đã được phân tích so sánh, làm cơ sở lựa chọn cho đề tài.

Đề tài Smart Gate hướng đến xây dựng *mô hình demo cấp prototype* của một thiết bị cổng AFC với cánh chắn quay, hỗ trợ 3 phương thức xác thực (Face + QR + RFID). Kiến trúc **dual-compute Pi 5 + ESP32** nối qua một dây USB-CDC đơn giản được chọn sau khi đánh giá 4 phương án – đây là điểm sáng tạo so với các đồ án sinh viên thường dùng đơn lẻ Pi hoặc đơn lẻ ESP32.

Chương tiếp theo (Chương 2) trình bày thiết kế phần cứng chi tiết: sơ đồ khối hệ thống, lựa chọn linh kiện, thiết kế từng khối, PCB carrier ESP32 và mô hình cơ khí cánh chắn.

---

# CHƯƠNG 2. THIẾT KẾ PHẦN CỨNG BỘ ĐIỀU KHIỂN CỔNG HỆ THỐNG AFC

## 2.1. Sơ đồ khối tổng thể của hệ thống

### 2.1.1. Sơ đồ khối tổng quát

Hệ thống Smart Gate được tổ chức thành hai khối tính toán chính (Pi 5 và ESP32) kết nối qua một dây cáp USB-CDC, mỗi khối liên kết với cụm ngoại vi riêng. Hình 2.1 thể hiện sơ đồ khối tổng quát.

```
┌────────────────────── Raspberry Pi 5 ───────────────────────┐
│                                                              │
│  USB Webcam ──▶ V4L2 (/dev/video0) ──▶ cv2.VideoCapture      │
│                                            │                 │
│                                            ▼                 │
│                                       FrameHub               │
│                                            │                 │
│                ┌───────────────┬───────────┴─────────┐       │
│                ▼               ▼                     ▼       │
│         Flask /stream     Detector              RingBuffer   │
│        .mjpeg endpoint   (MediaPipe +          (5s + 5s) →   │
│                          face_recognition       ffmpeg .mp4  │
│                          + pyzbar)                            │
│                ▲               │                              │
│                │               ▼                              │
│        Browser admin    SQLite DB (users,                    │
│        (LAN)            face_encodings,                       │
│                         qr_tokens, events)                    │
│                                                              │
│                  pyserial /dev/ttyUSB0 ◀──── esptool.py      │
└──────────────────────┬───────────────────────────────────────┘
                       │ USB cable (1 sợi, CP2102)
┌──────────────────────┴───────────────────────────────────────┐
│                  ESP32-WROOM-32 DevKit                       │
│                                                              │
│   CP2102 ─── UART0 ─── FreeRTOS tasks:                       │
│              (TX/RX)   - uart_link  (parse + emit JSON)      │
│                        - rfid       (poll RC522 50 ms)       │
│                        - sensor     (HC-SR04 50 ms)          │
│                        - gate_fsm   (state machine)          │
│                                                              │
│   NVS Preferences: authorized UIDs + runtime config          │
│   Wi-Fi: DISABLED                                            │
│                                                              │
│   ┌────────────────────────────────────────────────────┐    │
│   │ Carrier PCB (KiCad-designed):                      │    │
│   │  - RC522 (SPI)                                      │    │
│   │  - LCD 20×4 (I2C)                                   │    │
│   │  - HC-SR04 (TRIG/ECHO + voltage divider)            │    │
│   │  - SG90 servo (LEDC PWM 50 Hz)                      │    │
│   │  - Active buzzer (qua 2N3904)                       │    │
│   │  - Status LED (GPIO 2)                              │    │
│   │  - Đầu vào 12 V DC + buck + LDO                     │    │
│   └────────────────────────────────────────────────────┘    │
└──────────────────────────────────────────────────────────────┘
```

**Hình 2.1.** *Sơ đồ khối tổng quát hệ thống Smart Gate dual-compute.*

### 2.1.2. Chức năng từng khối

Bảng tóm tắt vai trò chính:

| Khối | Nền tảng | Chức năng chính |
|---|---|---|
| **Vision** | Pi 5 | Capture webcam, FrameHub fan-out, MediaPipe + face_recognition + pyzbar |
| **Data** | Pi 5 | SQLite WAL (users, face_encodings, qr_tokens, events, esp_log) |
| **Web admin** | Pi 5 | Flask HTTP server, MJPEG live preview, danh sách sự kiện, manual override |
| **Recorder** | Pi 5 | Ring buffer 5s + ffmpeg encode clip MP4 cho mỗi sự kiện |
| **CLI** | Pi 5 | python -m smart_gate.cli (enroll, users, qr, events) |
| **UART link** | Pi 5 ↔ ESP32 | JSON Lines @ 115200 baud, 8 cmd verbs + 6 evt verbs |
| **Real-time control** | ESP32 | 4 FreeRTOS tasks: uart_link, rfid, sensor, gate_fsm |
| **Peripherals** | ESP32 + carrier PCB | RC522 SPI, LCD I2C, Servo SG90 PWM, HC-SR04, buzzer |
| **NVS allowlist** | ESP32 | Preferences-backed UID/name store, max 100 entries |
| **Power** | Carrier PCB | 12 V DC → buck → 5 V → LDO → 3.3 V |
| **Mechanical** | Khung MDF + Servo | Hộp đáy 200×100×40 + 2 trụ 30×30×60 + cánh chắn 80 mm |

### 2.1.3. Phân chia trách nhiệm Pi 5 ↔ ESP32

Pi 5 đảm nhiệm các tác vụ **vision-heavy / non-real-time**:
- Đọc luồng video webcam, encode JPEG.
- Chạy MediaPipe Face Detection (~10 ms/khung).
- Chạy face_recognition embedding (~60–80 ms/khung).
- Chạy pyzbar decode QR (~5 ms/khung).
- Lưu trữ CSDL users, face encodings, QR tokens.
- Cung cấp web admin LAN.
- Ghi video sự kiện qua ffmpeg.

ESP32 đảm nhiệm các tác vụ **real-time / hardware control**:
- Đọc RC522 polling 50 ms/lần.
- Đo HC-SR04 polling 50 ms/lần, debounce 3 lần.
- Phát PWM 50 Hz điều khiển Servo SG90.
- Driver LCD I2C (truyền các text trạng thái).
- Driver buzzer qua 2N3904.
- Lưu danh sách thẻ RFID được phép trong NVS để hoạt động độc lập.

Giao tiếp giữa hai bên qua **giao thức JSON Lines trên USB-CDC** (chi tiết Chương 3 mục 3.3).

## 2.2. Lựa chọn thiết bị và linh kiện phần cứng

### 2.2.1. Tóm tắt linh kiện chính

**Bảng 2.1. Tóm tắt các linh kiện chính của hệ thống**

| Khối | Linh kiện | Vai trò | Số lượng |
|---|---|---|---|
| Tính toán Pi | Raspberry Pi 5 (4 GB hoặc 8 GB) | Vision, web, lưu trữ | 1 |
| Tính toán MCU | ESP32-WROOM-32 (DevKit DOIT V1 30-pin) | Điều khiển ngoại vi | 1 |
| Camera | Webcam USB UVC (Logitech C270) | Thu khuôn mặt + QR | 1 |
| Xác thực thẻ | Module RC522 + thẻ Mifare 13.56 MHz | Đọc UID qua SPI | 1 reader + ≥ 5 thẻ |
| Hiển thị | LCD 20×4 + backpack PCF8574 (I2C) | Hiển thị trạng thái | 1 |
| Cơ cấu chấp hành | Servo SG90 | Quay cánh chắn 0–100° | 1 |
| Cảm biến an toàn | HC-SR04 siêu âm | Phát hiện hành khách | 1 |
| Âm thanh | Active buzzer 5 V | Báo hiệu | 1 |
| Driver buzzer | NPN 2N3904 + R 1 kΩ | Tầng đệm dòng | 1 |
| Nguồn DC | Adapter 12 V / 2 A barrel jack | Cấp cho carrier | 1 |
| Buck | Module MP1584 hoặc LM2596 | 12 V → 5 V | 1 |
| LDO | AMS1117-3.3 | 5 V → 3.3 V | 1 |
| Tụ lọc | 470 µF (3×), 10 µF (2×) | Lọc nguồn | 5 |
| Diode bảo vệ | 1N5819 (anode-side) | Đảo cực bảo vệ | 1 |
| Diode flyback | 1N4148 | Flyback buzzer | 1 |
| Trở | 4.7 kΩ (2×), 1 kΩ (2×), 2 kΩ, 330 Ω | Pull-up I2C, chia áp ECHO, base, LED | 7 |
| Carrier PCB | KiCad 6.0.2 thiết kế | Tích hợp socket DevKit + đầu nối | 1 |
| Khung MDF | 3 mm laser-cut | Hộp đáy + 2 trụ + mặt trước/sau | 1 bộ |
| Cánh chắn | Balsa hoặc acrylic 80×8×3 mm | Quay 0–100° | 1 |
| Giá Servo | PLA in 3D | Gắn SG90 vào trụ | 1 |

### 2.2.2. Raspberry Pi 5

Raspberry Pi 5 (Hình 2.2) là dòng SBC thế hệ mới nhất của Raspberry Pi Foundation, ra mắt cuối 2023. So với Pi 4, Pi 5 dùng SoC Broadcom BCM2712 (4 nhân Cortex-A76 @ 2.4 GHz), GPU VideoCore VII, kèm chip Southbridge tùy chỉnh RP1 (toàn bộ I/O ngoại vi). Pi 5 được chọn (thay vì Pi 4 trong yêu cầu ban đầu) vì hiệu năng CPU/GPU cao hơn ~2–3 lần, đặc biệt quan trọng để chạy face_recognition theo thời gian thực.

**Bảng 2.2. Thông số kỹ thuật Raspberry Pi 5**

| Thông số | Giá trị |
|---|---|
| SoC | Broadcom BCM2712 (4 × Cortex-A76, 2.4 GHz) |
| GPU | VideoCore VII, hỗ trợ OpenGL ES 3.1, Vulkan 1.2 |
| RAM | 4 GB hoặc 8 GB LPDDR4X-4267 |
| Lưu trữ | microSD UHS-I + 1× PCIe 2.0 (cần HAT cho NVMe) |
| USB | 2× USB 3.0 + 2× USB 2.0 |
| Mạng | Gigabit Ethernet, Wi-Fi 5 dual-band, Bluetooth 5.0 |
| Camera | 2× MIPI CSI/DSI (cùng cổng) |
| GPIO | Header 40-pin chuẩn |
| Nguồn | USB-C PD 5 V/5 A (25 W) |

Vai trò trong hệ thống: chạy ứng dụng `smart_gate` (Python 3.11), kết nối webcam qua USB 3.0, kết nối ESP32 qua USB 2.0, kết nối mạng LAN cho web admin.

### 2.2.3. ESP32-WROOM-32 (DevKit DOIT V1 30-pin)

ESP32 (Hình 2.3) là dòng SoC microcontroller của Espressif, ra mắt 2016. Phiên bản classic ESP32-WROOM-32 (Xtensa LX6 dual-core) được chọn vì có sẵn FreeRTOS, đủ GPIO và giá rẻ. DevKit DOIT V1 30-pin là form-factor phổ biến nhất; tích hợp CP2102 USB-UART, nút EN/BOOT, LDO 3.3 V trên-board.

**Bảng 2.3. Thông số kỹ thuật ESP32-WROOM-32 (DOIT V1 30-pin)**

| Thông số | Giá trị |
|---|---|
| CPU | Xtensa LX6 dual-core, 240 MHz |
| RAM | 520 KB SRAM, 16 KB RTC SRAM |
| Flash | 4 MB (trên DevKit chuẩn) |
| Wi-Fi | 802.11 b/g/n (2.4 GHz) – **không dùng trong đề tài** |
| Bluetooth | BT 4.2 Classic + BLE – **không dùng** |
| GPIO | 25 chân khả dụng trên DevKit 30-pin |
| ADC | 18 kênh, 12-bit |
| PWM | LEDC controller, 16 kênh |
| SPI | 4 bộ (SPI0/SPI1 cho flash, HSPI và VSPI cho ứng dụng) |
| I2C | 2 bộ |
| UART | 3 bộ (UART0 cho debug, UART1, UART2) |

DOIT V1 30-pin **không expose** chân GPIO 18/19/21/22/23 (chân SPI/I2C mặc định) → cần dùng GPIO matrix để remap (xem mục 2.3 và Bảng 2.8).

### 2.2.4. Module RFID RC522

Module RC522 (Hình 2.4) dựa trên chip MFRC522 của NXP, làm việc ở 13.56 MHz (ISO/IEC 14443A) với khoảng đọc 3–5 cm cho thẻ Mifare Classic 1K phổ biến.

**Bảng 2.4. Thông số kỹ thuật module RFID RC522**

| Thông số | Giá trị |
|---|---|
| Tần số | 13.56 MHz |
| Giao thức thẻ | ISO/IEC 14443A (Mifare Classic, Ultralight, NTAG) |
| Khoảng đọc | 3–5 cm |
| Giao tiếp MCU | SPI (cũng hỗ trợ I2C/UART tùy module) |
| Điện áp | 3.3 V (không chịu được 5 V) |
| Dòng tiêu thụ | ~26 mA khi đang đọc |

Đề tài dùng UID 4 byte / 7 byte làm khóa primary trong NVS – không đọc nội dung block (đơn giản hóa, không cần authenticate sector).

### 2.2.5. Servo SG90

Servo SG90 (Hình 2.5) là động cơ servo RC nhỏ, phổ biến cho DIY.

**Bảng 2.5. Thông số kỹ thuật Servo SG90**

| Thông số | Giá trị |
|---|---|
| Điện áp | 4.8 – 6.0 V (dùng 5 V) |
| Mô-men xoắn | 1.8 kg·cm @ 4.8 V |
| Tốc độ quay | 60° trong 0.1 s (~300°/s) |
| Góc quay | 0° – 180° (ổn định 10° – 170°) |
| Điều khiển | PWM 50 Hz, độ rộng xung 1.0 – 2.0 ms |
| Dòng tiêu thụ | 100–200 mA; đỉnh ~500 mA tải nặng |

SG90 mô-men 1.8 kg·cm dư cho cánh chắn 80 mm balsa (yêu cầu < 0.3 kg·cm). Đề tài đổi từ MG996R (đề cập trong template) sang SG90 vì cánh chắn nhẹ – tiết kiệm dòng và chi phí (~30.000 đ so với ~150.000 đ).

### 2.2.6. Cảm biến siêu âm HC-SR04

HC-SR04 (Hình 2.6) là cảm biến siêu âm 40 kHz đo khoảng cách bằng thời gian phản hồi xung.

**Bảng 2.6. Thông số kỹ thuật cảm biến siêu âm HC-SR04**

| Thông số | Giá trị |
|---|---|
| Điện áp | 5 V (cần chia áp ECHO xuống 3.3 V cho ESP32) |
| Khoảng đo | 2 cm – 400 cm |
| Độ chính xác | ±3 mm |
| Tần số phát | 40 kHz |
| Dòng tiêu thụ | ~15 mA |
| Giao tiếp | 2 chân: TRIG (input) + ECHO (output) |

**Nguyên lý:**
1. MCU phát xung HIGH 10 µs trên TRIG.
2. Module phát 8 chu kỳ siêu âm 40 kHz.
3. Chân ECHO giữ HIGH trong khoảng thời gian tỉ lệ với khoảng cách: `d (cm) = t (µs) / 58`.
4. ESP32 dùng `pulseIn(PIN_ECHO, HIGH, 30000)` để đo (timeout 30 ms = 5 m).

ECHO ra mức 5 V → cần **chia áp R1 = 1 kΩ + R2 = 2 kΩ** giảm còn 3.3 V cho GPIO 34 (input-only). TRIG nhận 3.3 V vẫn trigger được (ngưỡng HIGH ~3 V).

### 2.2.7. LCD 20×4 (PCF8574 I2C backpack)

LCD 20×4 ký tự (Hình 2.7) – 4 dòng × 20 ký tự – với backpack PCF8574 chuyển từ giao tiếp song song HD44780 sang I2C 4 dây.

**Bảng 2.7. Thông số kỹ thuật LCD 20×4 (PCF8574 I2C backpack)**

| Thông số | Giá trị |
|---|---|
| Kích thước hiển thị | 20 cột × 4 dòng |
| Driver nội | HD44780 |
| Driver backpack | PCF8574 (I2C expander) |
| Địa chỉ I2C | 0x27 (mặc định) hoặc 0x3F |
| Điện áp | VCC 5 V; tín hiệu I2C có thể chạy 3.3 V nếu pull-up về 3.3 V |
| Backlight | LED on/off bằng jumper |
| Tốc độ I2C | 100 kHz (Standard) hoặc 400 kHz (Fast) |

**Vấn đề I2C 5 V:** backpack PCF8574 có pull-up 4.7 kΩ về 5 V → back-drive vào ESP32 3.3 V GPIO. **Giải pháp:** cắt 2 trở pull-up trên backpack, gắn 2 trở 4.7 kΩ về 3.3 V trên carrier PCB.

### 2.2.8. Buzzer và mạch driver

**Active buzzer** (loại có dao động nội bộ): GPIO HIGH → buzzer phát ~2 kHz; GPIO LOW → tắt. Tần số đầu ra cố định bởi mạch dao động trong buzzer, MCU chỉ điều khiển on/off.

Dòng buzzer ~25 mA vượt ngưỡng GPIO ESP32 (12 mA) → cần transistor NPN làm tầng đệm:
- **2N3904** với base resistor 1 kΩ.
- Emitter → GND, Collector → âm buzzer, dương buzzer → 5 V.
- Khi GPIO HIGH (3.3 V), transistor dẫn → buzzer kêu.

### 2.2.9. Khối nguồn

- **Đầu vào:** adapter AC-DC 12 V / 2 A barrel jack 5.5/2.1 mm.
- **Diode bảo vệ 1N5819:** chống đảo cực adapter.
- **Buck MP1584:** 12 V → 5 V, hiệu suất ~85%, dòng đầu ra ≤ 3 A.
- **LDO AMS1117-3.3:** 5 V → 3.3 V, dòng tối đa 1 A (đề tài chỉ cần ~150 mA).
- **Tụ lọc:** C1 470 µF/25 V đầu vào buck, C2 470 µF/16 V đầu ra (gần Servo), C3+C4 10 µF cho LDO.

## 2.3. Thiết kế chi tiết phần cứng bộ điều khiển cổng

Phần này thiết kế từng khối chức năng dẫn đến sơ đồ nguyên lý tổng thể của bo carrier ESP32 (Hình 2.8).

### 2.3.1. Khối nguồn

Sơ đồ khối nguồn:

```
12 V DC ─▶ J1 (barrel jack) ─▶ D1 (1N5819) ─▶ +12V_IN
                                                  │
                                                  ▼
                                          [Buck MP1584]
                                          VIN  EN  VOUT  GND
                                            │   ▲    │
                                            │   │    ├──▶ +5V rail
                                            │  3.3V          │
                                            │ (pull-up)      ├──▶ C2 470 µF
                                            │                │
                                            │                ▼
                                            │           [LDO AMS1117-3.3]
                                            │            VIN  OUT  GND
                                            │              │    │
                                            │              │    ├──▶ +3.3V rail
                                            │              │
                                            └──── C1 470 µF
                                            (đầu vào buck)
```

- **D1 1N5819 Schottky** (Vf ~0.3 V) bảo vệ đảo cực, đặt anode-side đường +12V.
- **C1 470 µF/25 V** lọc nhiễu thấp tần đầu vào buck.
- **Buck MP1584** điều chỉnh xuống 5 V; EN-pin pull-up 10 kΩ về 3.3 V để bật mặc định.
- **C2 470 µF/16 V** đặt sát chân Servo trên rail 5 V để hấp thụ inrush 500 mA của SG90.
- **LDO AMS1117-3.3** chuyển 5 V → 3.3 V cho ESP32 + RC522; tụ C3 (10 µF tantalum) đầu vào, C4 (10 µF) đầu ra.
- Ground topology: ground duy nhất (single-point ground) trên PCB, tránh ground loop.

### 2.3.2. Khối ESP32 socket

ESP32 DevKit DOIT V1 30-pin được cắm vào hai hàng socket header female 15-chân nằm dọc carrier. Đầu cấp nguồn cho DevKit từ rail 5 V của carrier (qua chân VIN của DevKit) – LDO 3.3 V on-board của DevKit sẽ tự cấp 3.3 V cho ESP32, nhưng đề tài **không** dùng nguồn 3.3 V của DevKit cho RC522 (vì dòng ~30 mA của RC522 vượt giới hạn ổn định của LDO trên-board). Thay vào đó, RC522 nhận 3.3 V từ AMS1117 trên carrier.

### 2.3.3. Khối RFID RC522 (SPI)

Sơ đồ kết nối:

```
ESP32 (carrier)                    Module RC522 (J2 header 8-chân)
─────────────                       ─────────────────────────────
GPIO 14 (SCK)    ─────────────────▶ SCK
GPIO 13 (MOSI)   ─────────────────▶ MOSI
GPIO 35 (MISO)   ◀───────────────── MISO
GPIO 15 (CS)     ─────────────────▶ SDA (= CS trên module)
GPIO 4  (RST)    ─────────────────▶ RST
GPIO 16 (IRQ)    ◀───────────────── IRQ (tùy chọn; polling mode)
+3.3V            ─────────────────▶ VCC (3.3V – KHÔNG 5V)
GND              ─────────────────▶ GND
```

Lưu ý:
- Vì DOIT V1 30-pin **không** expose chân SPI mặc định (18/19/21/23), đề tài remap qua GPIO matrix: SCK=14, MOSI=13, MISO=35, CS=15.
- GPIO 35 là input-only → phù hợp cho MISO (luôn input).
- GPIO 15 là strap-HIGH-at-boot → tương thích với CS idle HIGH.
- Tần số SPI: 4 MHz (mặc định MFRC522 library) – thừa cho ứng dụng đọc 13.56 MHz card.

### 2.3.4. Khối LCD 20×4 (I2C)

Sơ đồ kết nối:

```
ESP32              Carrier PCB         LCD 20×4 backpack (J3 4-chân)
─────              ───────────         ──────────────────────────────
GPIO 32 (SDA) ──┬─ R1 4.7kΩ ─ +3.3V    SDA
                │
                └──────────────────▶   SDA
GPIO 33 (SCL) ──┬─ R2 4.7kΩ ─ +3.3V    SCL
                │
                └──────────────────▶   SCL
+5V (rail)    ──────────────────────▶  VCC (5V)
GND           ──────────────────────▶  GND
```

- **Pull-up 4.7 kΩ về 3.3 V** trên carrier (R1, R2) – đảm bảo bus I2C swing đầy đủ giữa 3.3 V và GND.
- **Cắt bỏ pull-up gốc 5 V** trên backpack PCF8574 (note assembly).
- Tần số I2C: 100 kHz (Standard mode) – đủ cho LCD HD44780.

### 2.3.5. Khối HC-SR04

Sơ đồ kết nối:

```
ESP32                              HC-SR04 (J4 4-chân)
─────                              ────────────────────
+5V (rail) ──────────────────────▶ VCC
GND        ──────────────────────▶ GND
GPIO 25 (TRIG)  ─────────────────▶ TRIG (3.3V đủ trigger)
                ┌─── R3 1kΩ ────┐
GPIO 34 (ECHO) ◀┤               │── ECHO (5V output)
   (input-only) │   R4 2kΩ      │
                └───── GND ──────┘
```

- **Chia áp ECHO:** R3 = 1 kΩ + R4 = 2 kΩ giảm ECHO từ 5 V → 5 × (2/3) = 3.33 V.
- TRIG: ESP32 3.3 V trực tiếp đến module – đa số HC-SR04 ngưỡng HIGH ~3 V, hoạt động OK.
- Nếu HC-SR04 không trigger ổn định, có thể thêm BS170 MOSFET làm level shifter (option dự phòng).

### 2.3.6. Khối Servo SG90

Sơ đồ kết nối:

```
ESP32                              SG90 (J5 3-chân)
─────                              ─────────────────
GPIO 26 (PWM) ───────────────────▶ SIG (vàng)
+5V (rail)    ──┬────────────────▶ VCC (đỏ)
                │
                ├─ C2 470 µF/16V ─ GND  (sát chân Servo trên PCB)
                │
GND           ──┴────────────────▶ GND (nâu)
```

- **PWM** từ LEDC kênh 0, tần số 50 Hz, độ rộng xung 1.0 ms (0°) đến 2.0 ms (180°).
- ESP32 3.3 V đủ trigger ngưỡng HIGH của SG90.
- C2 hấp thụ dòng đỉnh 500 mA của SG90 khi bắt đầu quay.

### 2.3.7. Khối Buzzer

Sơ đồ kết nối:

```
+5V ────┬───┬─ Buzzer (+) ──┐
        │   │                │
        │   D2 1N4148        │
        │   (cathode lên)    │
        │   │                │
        │   └────────────┬───┤
                          │
                          ▼
                  Buzzer (–) ─ Collector
                                Q1 2N3904 NPN
GPIO 27 ── R5 1kΩ ── Base
                                Emitter ─ GND
```

- **2N3904 NPN** tầng đệm dòng buzzer 25 mA.
- **R5 = 1 kΩ** giới hạn dòng base.
- **D2 1N4148** flyback bảo vệ khi tắt buzzer (mặc dù active buzzer có dao động nội nên flyback ít cần thiết, vẫn để đề phòng).

### 2.3.8. LED trạng thái

```
GPIO 2 ── R6 330Ω ── LED ── GND
```

LED on-board của DevKit đã có sẵn ở GPIO 2 – đề tài dùng luôn, không cần LED ngoài.

### 2.3.9. Header mở rộng

J6 (6-chân) cho mở rộng tương lai:
- Pin 1: +3.3 V
- Pin 2: GND
- Pin 3: GPIO 17
- Pin 4: GPIO 5
- Pin 5: GPIO 36 (ADC1 capable)
- Pin 6: GPIO 39 (ADC1 capable)

GPIO 12 *không* được bring out vì strap LOW-at-boot.

### 2.3.10. Bảng phân chân ESP32 chi tiết

**Bảng 2.8. Phân bố chân (Pin assignment) trên ESP32 DOIT V1 30-pin**

| GPIO | Hướng | Ngoại vi | Ghi chú |
|---|---|---|---|
| 1 | OUT | UART0 TX (USB-CDC) | Dành riêng |
| 3 | IN | UART0 RX (USB-CDC) | Dành riêng |
| 2 | OUT (strap) | LED trạng thái | Không pull HIGH tại boot |
| 14 | OUT | RC522 SCK | VSPI remap |
| 13 | OUT | RC522 MOSI | VSPI remap |
| 35 | IN-only | RC522 MISO | Input-only OK cho MISO |
| 15 | OUT (strap) | RC522 CS | Strap HIGH OK (CS idle HIGH) |
| 4 | OUT | RC522 RST | Active LOW khi reset |
| 16 | IN | RC522 IRQ | Polling mode không dùng |
| 32 | I/O | LCD I2C SDA | Pull-up 4.7 kΩ về **3.3 V** |
| 33 | OUT | LCD I2C SCL | Pull-up 4.7 kΩ về **3.3 V** |
| 25 | OUT | HC-SR04 TRIG | Xung 10 µs |
| 34 | IN-only | HC-SR04 ECHO | **Phải có chia áp** R1=1k, R2=2k |
| 26 | OUT | Servo SG90 PWM | LEDC kênh 0, 50 Hz |
| 27 | OUT | Active buzzer | Qua 2N3904 + 1 kΩ |
| 6–11 | – | **KHÔNG SỬ DỤNG** | Nối với flash nội |
| 12 | – | **KHÔNG SỬ DỤNG** | Strap LOW at boot |
| 17, 5, 36, 39 | – | Mở rộng | Header J6 |

### 2.3.11. Ước tính dòng tiêu thụ

**Bảng 2.9. Ước tính dòng điện tiêu thụ trên các đường nguồn**

| Đường nguồn | Tải | Dòng đỉnh ước tính |
|---|---|---|
| 3.3 V | ESP32 (120 mA) + RC522 (30 mA) | ~150 mA |
| 5 V | LCD + backlight (50 mA) + HC-SR04 (15 mA) + SG90 (đỉnh 500 mA) + Buzzer (25 mA) | ~600 mA đỉnh |
| 12 V (sau buck ~85% hiệu suất) | (600 mA × 5 V) / (12 V × 0.85) | ~300 mA |

Adapter 12 V/2 A dư so với yêu cầu 300 mA – đảm bảo dự phòng khi thêm ngoại vi.

### 2.3.12. Sơ đồ nguyên lý tổng thể

Sơ đồ nguyên lý đầy đủ được vẽ trong KiCad 6.0.2, lưu tại `kicad/smart_gate_carrier/smart_gate_carrier.kicad_sch` (đơn-sheet). ERC (Electrical Rules Check) đã chạy và clean.

**Hình 2.8.** *Sơ đồ nguyên lý mạch carrier ESP32 (KiCad).*

Sơ đồ tích hợp:
1. ESP32 DevKit socket (2 × 15-pin headers).
2. Khối nguồn (J1 + D1 + MP1584 + AMS1117 + tụ lọc).
3. Khối RC522 (J2 8-chân).
4. Khối LCD (J3 4-chân + pull-up 3.3 V).
5. Khối HC-SR04 (J4 4-chân + chia áp).
6. Khối Servo (J5 3-chân + C2).
7. Khối Buzzer (J7 2-chân + Q1 + R5 + D2).
8. Header mở rộng J6 6-chân.
9. LED status (D3 + R6).

## 2.4. Thiết kế PCB mạch điều khiển và mô hình thiết bị cổng

### 2.4.1. Thiết kế PCB

**Thông số PCB:**
- Kích thước: 80 × 60 mm
- Số lớp: 2 (top + bottom)
- Độ rộng đường tín hiệu: 0.25 mm
- Độ rộng đường nguồn: 0.5 mm
- Via: 0.6/0.3 mm
- Bề mặt: HASL chì hoặc HASL không chì
- Soldermask: xanh (mặc định)
- Silkscreen: trắng

**Bố trí (floorplan):**
- Vùng nguồn (J1, D1, buck, LDO, tụ lọc): góc trái – tách riêng để giảm nhiễu cấp nguồn.
- ESP32 socket: chính giữa – các đầu nối ngoại vi tỏa ra ngoài.
- J2 RC522, J3 LCD, J4 HC-SR04, J5 Servo, J7 Buzzer: bố trí dọc 2 cạnh dài để dễ đi cáp ra ngoài.
- J6 expansion: ở cạnh ngắn.
- LED status: cạnh ngắn còn lại, cùng phía với nút điều khiển.

**Lưu ý layout:**
- Toàn bộ linh kiện chân cắm xuyên lỗ (THT) – không SMD – để dễ hàn tay và sửa.
- Tụ C2 470 µF/16V đặt sát chân Servo, đường +5V đến Servo rộng 1.0 mm để chịu dòng đỉnh 500 mA.
- Đường GND đổ poly fill 2 lớp.
- Khoảng cách tối thiểu giữa các đường: 0.2 mm (theo IPC-2221 cho 25 V); thực tế giữ ≥ 0.3 mm.

**Hình 2.9.** *Sơ đồ mạch in (PCB) 2D mặt trước/mặt sau.*

**Hình 2.10.** *Mô hình 3D PCB carrier.*

(Việc layout PCB là pha tiếp theo của plan KiCad `2026-05-22-kicad-schematic.md`; schematic đã hoàn thành. PCB sẽ tạo từ netlist của schematic.)

### 2.4.2. Mô hình cơ khí thiết bị cổng (FreeCAD)

Mô hình cơ khí được dựng trong FreeCAD 0.21, file `mechanical/smart_gate_assembly.FCStd`.

**Thông số tham số (Spreadsheet):**

| Tham số | Giá trị | Mô tả |
|---|---|---|
| base_w | 200 mm | Rộng thân hộp |
| base_d | 100 mm | Sâu thân hộp |
| base_h | 40 mm | Cao thân hộp |
| post_w | 30 mm | Cạnh trụ |
| post_h | 60 mm | Cao trụ |
| arm_len | 80 mm | Chiều dài cánh chắn |
| lane_w | 60 mm | Rộng lane đi |

**Các chi tiết:**

| Chi tiết | Kích thước (mm) | Vật liệu | Ghi chú |
|---|---|---|---|
| Hộp đáy | 200 × 100 × 40 | MDF 3 mm | Chứa Pi 5 + carrier PCB + buck + cáp |
| Trụ trái (gắn Servo) | 30 × 30 × 60 | MDF 3 mm 6 panel | Servo nằm ngang, horn hướng phải |
| Trụ phải (đỡ) | 30 × 30 × 60 | MDF 3 mm 6 panel | Pad foam đệm khi cánh chắn nghỉ |
| Cánh chắn | 80 × 8 × 3 | Balsa hoặc acrylic | Sơn sọc đỏ/vàng |
| Giá Servo | ~25 × 25 × 25 | PLA in 3D | 2 lỗ M3 cho SG90 |
| Giá camera | dia 8 × 250 + đế 80 × 80 | Cọc gỗ + đế MDF | Nghiêng 30° xuống lane |
| Mặt trước hộp | 200 × 40 | MDF 3 mm | Khoét lỗ LCD 98×24, RC522 60×40, HC-SR04 2×Ø16, LED Ø3, Buzzer Ø8 |
| Mặt sau hộp | 200 × 40 | MDF 3 mm | Lỗ jack DC Ø8, USB-C Pi 14×6, 4 khe tản nhiệt |

**Hình 2.11.** *Bản vẽ cơ khí khung cổng (FreeCAD).*

### 2.4.3. Đầu ra FreeCAD

| File | Loại | Mục đích |
|---|---|---|
| `smart_gate_assembly.FCStd` | Parametric assembly | Top-level, spreadsheet-driven |
| `panels.FCStd` | 2D sketches | Một sketch cho mỗi panel cắt laser, export DXF |
| `servo_bracket.FCStd` | 3D solid | Export STL cho 3D print |
| `arm_coupling.FCStd` | 3D solid (option) | Nếu không gắn cánh trực tiếp lên horn |
| `step_export/*.step` | Auto export | Cho KiCad 3D viewer xác minh PCB vừa khung |

### 2.4.4. Trình tự thi công và lắp ráp

1. Cắt laser các panel MDF từ file DXF (export từ FreeCAD).
2. In 3D giá Servo (PLA, infill 30%, layer 0.2 mm).
3. Gắn SG90 vào giá, gắn giá vào trụ trái bằng vít M3.
4. Gắn cánh chắn vào horn Servo (vít M2 + keo).
5. Đặt PCB carrier đặt sản xuất tại xưởng (gerber export từ KiCad).
6. Hàn linh kiện lên PCB carrier theo BOM.
7. Cắm ESP32 DevKit vào socket carrier, nối ngoại vi qua header XH/Dupont.
8. Cố định carrier PCB và Pi 5 vào đáy hộp bằng cột bằng ốc M2.5.
9. Cắt cửa sổ mặt trước cho LCD, RC522, HC-SR04, LED, buzzer.
10. Gắn webcam lên giá camera; nối cáp USB từ webcam đến cổng USB 3.0 Pi.
11. Nối cáp USB từ Pi đến DevKit ESP32 (cùng cáp dùng cho nạp firmware).
12. Cắm jack DC 12 V vào mặt sau, cấp nguồn carrier.
13. Cấp nguồn USB-C 5 V/5 A cho Pi.

**Hình 2.12.** *Mô hình lắp ráp thực tế.*

## 2.5. Kết luận chương 2

Chương 2 đã trình bày toàn bộ thiết kế phần cứng cho bộ điều khiển cổng AFC Smart Gate, từ sơ đồ khối tổng thể đến chi tiết từng cụm: nguồn 12 V → 5 V → 3.3 V, khối RC522 SPI (remap GPIO matrix), khối LCD I2C 20×4 (pull-up về 3.3 V), khối HC-SR04 (chia áp ECHO), khối Servo SG90 PWM, khối buzzer (đệm 2N3904), khối ESP32 DevKit và header mở rộng.

Phân bố chân ESP32 đã được điều chỉnh phù hợp với DevKit DOIT V1 30-pin (Bảng 2.8) – đây là điểm quan trọng cần lưu ý vì DOIT V1 30-pin không expose chân SPI/I2C mặc định. Ước tính dòng tiêu thụ (Bảng 2.9) cho thấy adapter 12 V/2 A dư so với yêu cầu.

Sơ đồ nguyên lý KiCad đã pass ERC; PCB layout là pha tiếp theo. Mô hình cơ khí FreeCAD parametric với cánh chắn quay 90° bằng MDF + Servo SG90 + giá PLA in 3D đảm bảo demo cấp prototype hoạt động ổn định.

Chương tiếp theo (Chương 3) sẽ trình bày phần thiết kế phần mềm điều khiển và xử lý dữ liệu AFC trên cả Pi 5 và ESP32, bao gồm yêu cầu phần mềm, cơ sở dữ liệu, thuật toán điều khiển và giao diện giám sát.

---

# CHƯƠNG 3. THIẾT KẾ PHẦN MỀM ĐIỀU KHIỂN VÀ XỬ LÝ DỮ LIỆU AFC

## 3.1. Các yêu cầu của phần mềm điều khiển và xử lý dữ liệu

### 3.1.1. Yêu cầu chức năng

Phần mềm Smart Gate phải đáp ứng các yêu cầu chức năng:

1. **Nhận diện vé đa phương thức:**
   - Đọc thẻ RFID 13.56 MHz → tra cứu allowlist → quyết định cho qua/từ chối.
   - Quét mã QR từ webcam → tra cứu DB QR tokens → quyết định.
   - Phát hiện + nhận diện khuôn mặt từ webcam → so khớp với DB face encodings → quyết định.
2. **Kiểm tra tính hợp lệ vé:**
   - Thẻ RFID phải có UID trong allowlist.
   - QR token phải tồn tại trong DB và chưa bị revoked.
   - Embedding khuôn mặt phải gần (Euclidean distance < threshold) với một user trong DB.
3. **Điều khiển cánh chắn:**
   - Khi xác thực thành công, mở cánh chắn (Servo 100°).
   - Khi hành khách đã đi qua, đóng cánh chắn (Servo 10°).
   - Khi xác thực thất bại, không mở.
   - Khi không phát hiện hành khách đi qua sau 10 s, cảnh báo + tự đóng.
4. **Ghi nhật ký giao dịch (transaction log):**
   - Mỗi xác thực (granted hay denied) → 1 dòng trong bảng `events`.
   - Lưu kèm timestamp, phương thức, user_id, kết quả.
   - Lưu clip video sự kiện 10 giây (5 s pre + 5 s post).
5. **Truyền dữ liệu về trung tâm (mô phỏng):**
   - Trong đề tài demo, "trung tâm" là chính máy Pi (local SQLite). Trong production, dữ liệu sẽ truyền qua REST API/MQTT về Station Controller.
6. **Giao diện giám sát:**
   - Web admin LAN xem MJPEG live preview + danh sách sự kiện.
   - Manual override (mở/đóng cổng từ web).
   - Health check.
7. **Quản trị người dùng (CLI):**
   - Enroll user mới với 5 mẫu khuôn mặt + sinh QR token.
   - Liệt kê / xóa user.
   - Rotate / revoke QR token.

### 3.1.2. Yêu cầu phi chức năng

| Tiêu chí | Mục tiêu |
|---|---|
| Độ trễ xác thực RFID | < 500 ms từ áp thẻ đến cổng mở |
| Độ trễ xác thực QR | < 1 s |
| Độ trễ xác thực khuôn mặt | < 2 s |
| FPS detector | ≥ 8 fps |
| Độ chính xác face (≥ 300 lux) | ≥ 90% trong 10 lần thử |
| Tỉ lệ false positive RFID | 0% (UID phải khớp exact) |
| Độ ổn định UART | 0 missed ACK trong 5760 ping (8 giờ liên tục) |
| Khả năng phục hồi | Standalone resilience – ESP32 hoạt động không Pi |
| Khả năng restart | systemd restart-on-failure |
| Quan sát (observability) | Mỗi state transition + lỗi đều phát evt:log |

### 3.1.3. Nền tảng phần cứng và ngôn ngữ lập trình

| Nền tảng | OS / Framework | Ngôn ngữ | Build tool |
|---|---|---|---|
| Raspberry Pi 5 | Raspberry Pi OS Bookworm 64-bit | Python 3.11 | venv + pip |
| ESP32-WROOM-32 | Arduino-ESP32 trên FreeRTOS | C/C++ (Arduino sketch + module .cpp) | PlatformIO |

### 3.1.4. Kiến trúc phần mềm tổng thể

**Trên Pi 5:** một tiến trình Python (`python -m smart_gate`) chạy 8 luồng (Hình 3.1), systemd quản lý lifecycle. Một tiến trình CLI riêng (`python -m smart_gate.cli`) phục vụ enroll/QR/users/events. Đồng bộ giữa daemon và CLI qua SQLite + signal SIGUSR1.

```
systemd: smart-gate.service
    │
    ▼ python -m smart_gate (1 tiến trình, 8 luồng)
    │
    ├── cap          – cv2 V4L2 capture
    ├── detect       – MediaPipe + face_recognition + pyzbar
    ├── rec          – Ring buffer + ffmpeg
    ├── rx           – pyserial reader
    ├── tx           – pyserial writer
    ├── heartbeat    – cmd:ping every 5s
    ├── flask        – werkzeug threaded server
    └── watchdog     – tick monitor threads 1–7
```

**Hình 3.1.** *Kiến trúc phần mềm trên Pi 5 (8 luồng).*

**Bảng 3.1. Danh sách 8 luồng (thread) trong tiến trình Pi 5**

| # | Tên | Module | Vai trò |
|---|---|---|---|
| 1 | cap | video/capture.py | cv2.VideoCapture loop, encode JPEG, publish FrameHub |
| 2 | detect | recognition/detector.py | MediaPipe + face_recognition + pyzbar, phát AuthEvent |
| 3 | rec | video/recorder.py | Ring buffer, ffmpeg encode |
| 4 | rx | link/uart_client.py | Đọc /dev/ttyUSB0, parse JSON, dispatch |
| 5 | tx | link/uart_client.py | Serialize tx_queue → port (single writer) |
| 6 | heartbeat | link/uart_client.py | cmd:ping mỗi 5 s |
| 7 | flask | web/app.py | Werkzeug threaded server bound 0.0.0.0:8080 |
| 8 | watchdog | main.py | Tick-monitor threads 1–7, WARN nếu stale > 30 s |

**Trên ESP32:** firmware Arduino-ESP32 với 4 FreeRTOS task pinned core.

**Bảng 3.2. Mô hình tác vụ FreeRTOS trên ESP32**

| Task | Stack | Priority | Core | Trách nhiệm |
|---|---|---|---|---|
| `uart_link_task` | 4096 B | 3 | 0 | Đọc Serial byte-by-byte, parse JSON, đẩy event_t; drain outbound_q |
| `rfid_task` | 3072 B | 2 | 1 | Polling MFRC522 mỗi 50 ms |
| `sensor_task` | 2048 B | 2 | 1 | Polling HC-SR04 mỗi 50 ms, debounce 3-count |
| `gate_fsm_task` | 4096 B | 4 | 1 | Đọc event_q, chạy FSM, gọi driver Servo/LCD/Buzzer |

Lý do **không** tạo task riêng cho Servo/LCD/Buzzer: các driver này non-blocking (Servo.write() trả về ngay, LCD I2C transaction ~5 ms, buzzer_beep_ok() chỉ 80 ms). Tạo task riêng tốn ~9 KB stack mà không tăng độ phản hồi.

### 3.1.5. Module layout Python

```
smart_gate/
├── __init__.py
├── __main__.py             # entry: python -m smart_gate
├── main.py                 # orchestrator
├── config.py               # tomllib loader + defaults
├── video/
│   ├── capture.py          # cv2 V4L2 thread
│   ├── framehub.py         # threading.Condition fan-out
│   └── recorder.py         # ring buffer + ffmpeg + cleanup
├── recognition/
│   ├── detector.py         # MediaPipe + face_recognition + pyzbar
│   └── matcher.py          # in-memory index, reload on SIGUSR1
├── link/
│   ├── uart_client.py      # rx/tx/heartbeat threads
│   └── protocol.py         # JSON Lines codec (pure functions)
├── web/
│   ├── app.py              # Flask app factory + routes
│   ├── templates/          # base, dashboard, users
│   └── static/             # htmx.min.js, pico.min.css
├── data/
│   ├── db.py               # connection pool
│   ├── models.py           # dataclasses User, Event, FaceEncoding, QrToken
│   └── migrations/0001_init.sql
└── cli/
    ├── enroll.py
    ├── qr.py
    ├── users.py
    └── events.py
```

## 3.2. Thiết kế cơ sở dữ liệu

### 3.2.1. Mô hình dữ liệu

Cơ sở dữ liệu Smart Gate dùng SQLite (chế độ WAL – Write-Ahead Logging) trên Pi 5, gồm 5 bảng:

- **users:** danh sách hành khách đăng ký (định danh sinh trắc + QR; RFID là độc lập).
- **face_encodings:** các vector 128 chiều biểu diễn khuôn mặt của user (mỗi user 3–5 mẫu).
- **qr_tokens:** danh sách QR token đang/đã sử dụng (1 token active/user).
- **events:** nhật ký giao dịch – mỗi xác thực (hợp lệ hay không) là 1 dòng.
- **esp_log:** log từ ESP32 (mirrored từ evt:log).

Sơ đồ quan hệ thực thể (ER):

```
┌─────────────────┐ 1     N ┌──────────────────┐
│ users           │◀────────│ face_encodings   │
│  id (PK)        │         │  id (PK)         │
│  name UNIQUE    │         │  user_id (FK)    │
│  created_at     │         │  embedding BLOB  │
│  last_seen      │         │  sample_idx      │
│  note           │         │  created_at      │
└─────────────────┘         └──────────────────┘
        ▲ 1
        │ N
┌─────────────────┐
│ qr_tokens       │
│  token (PK)     │
│  user_id (FK)   │
│  created_at     │
│  revoked_at     │
└─────────────────┘
        ▲ 0..1
        │ N
┌─────────────────┐
│ events          │
│  id (PK)        │
│  ts             │
│  method         │  -- 'face'|'qr'|'rfid'|'manual_open'|'manual_close'
│  user_id (FK)   │
│  granted        │
│  detail JSON    │
│  clip_path      │
└─────────────────┘

┌─────────────────┐
│ esp_log         │  (đứng độc lập, không khoá ngoại)
│  id (PK)        │
│  ts             │
│  lvl            │
│  tag            │
│  msg            │
└─────────────────┘
```

**Hình 3.3.** *Sơ đồ quan hệ thực thể (ER) cơ sở dữ liệu SQLite.*

### 3.2.2. Schema SQL chi tiết

File `data/migrations/0001_init.sql`:

```sql
PRAGMA journal_mode=WAL;
PRAGMA foreign_keys=ON;
PRAGMA busy_timeout=5000;

CREATE TABLE users (
    id          INTEGER PRIMARY KEY AUTOINCREMENT,
    name        TEXT    NOT NULL UNIQUE,
    created_at  TEXT    NOT NULL DEFAULT (datetime('now')),
    last_seen   TEXT,
    note        TEXT
);

CREATE TABLE face_encodings (
    id          INTEGER PRIMARY KEY AUTOINCREMENT,
    user_id     INTEGER NOT NULL REFERENCES users(id) ON DELETE CASCADE,
    embedding   BLOB    NOT NULL,     -- 128 × float32 = 512 byte
    sample_idx  INTEGER NOT NULL,
    created_at  TEXT    NOT NULL DEFAULT (datetime('now'))
);
CREATE INDEX idx_face_user ON face_encodings(user_id);

CREATE TABLE qr_tokens (
    token       TEXT    PRIMARY KEY,   -- 32 ký tự hex (16 byte random)
    user_id     INTEGER NOT NULL REFERENCES users(id) ON DELETE CASCADE,
    created_at  TEXT    NOT NULL DEFAULT (datetime('now')),
    revoked_at  TEXT
);
CREATE UNIQUE INDEX idx_qr_active_user
    ON qr_tokens(user_id) WHERE revoked_at IS NULL;

CREATE TABLE events (
    id          INTEGER PRIMARY KEY AUTOINCREMENT,
    ts          TEXT    NOT NULL DEFAULT (datetime('now')),
    method      TEXT    NOT NULL,      -- 'face' | 'qr' | 'rfid' | 'manual_open' | 'manual_close'
    user_id     INTEGER REFERENCES users(id) ON DELETE SET NULL,
    granted     INTEGER NOT NULL,      -- 0 | 1
    detail      TEXT,                  -- JSON
    clip_path   TEXT
);
CREATE INDEX idx_events_ts ON events(ts DESC);

CREATE TABLE esp_log (
    id   INTEGER PRIMARY KEY AUTOINCREMENT,
    ts   TEXT NOT NULL DEFAULT (datetime('now')),
    lvl  TEXT NOT NULL,                -- 'info' | 'warn' | 'err'
    tag  TEXT,
    msg  TEXT NOT NULL
);
```

### 3.2.3. Các quyết định thiết kế DB

- **3–5 mẫu khuôn mặt/người** (cải thiện độ chính xác khi mặt nghiêng / ánh sáng khác); mỗi mẫu lưu thành 1 dòng. Lookup trả về `min(distance)` qua tất cả mẫu của user.
- **Embedding 128 float32 = 512 byte/dòng**; load `numpy.frombuffer(blob, dtype='float32')`. Toàn bộ ≤ 200 mẫu load vào RAM ngay lúc khởi động.
- **1 QR token active/user** enforce bởi partial unique index `WHERE revoked_at IS NULL`. Rotate = revoke cũ + insert mới trong cùng transaction.
- **Sự kiện RFID** từ ESP32 cũng được mirror vào bảng `events` (`method='rfid'`) để có nhật ký thống nhất – truy vấn nhật ký không cần JOIN nhiều nguồn.
- **Stranger events** (face không match) ghi `user_id=NULL, granted=0`. Debouncer chống spam.
- **`esp_log` tách riêng** từ `events` để log spam không làm lẫn entry history; rotated by row count (giữ 10.000 dòng gần nhất).
- **Index trên `events.ts DESC`** để truy vấn 50 sự kiện gần nhất nhanh.
- **WAL mode** giảm tranh chấp khoá giữa các thread; `busy_timeout=5000` ms phòng deadlock đơn lẻ.

### 3.2.4. Cơ sở dữ liệu trên ESP32 (NVS Preferences)

ESP32 lưu danh sách thẻ RFID được phép trong **NVS namespace `allowlist`**:
- 1 key/UID hex (8 ký tự), value = name (≤ 32 char).
- Key đặc biệt `_index` = JSON array các UIDs, để hỗ trợ `cmd:list_uids` (NVS không có API enumerate cho Preferences keys).
- Giới hạn `ALLOWLIST_MAX_ENTRIES = 100`.

NVS namespace `config`:
- `close_timeout_s` (int) – default 10
- `servo_open_deg` (int) – default 100
- `servo_close_deg` (int) – default 10

Mọi mutation NVS được serialize qua `gate_fsm_task` (single writer) – không cần lock thêm.

### 3.2.5. Luồng dữ liệu toàn hệ thống

```
[Webcam] ──UVC──▶ [Pi 5: cap] ──BGR──▶ [FrameHub]
                                            │
                            ┌───────────────┼─────────────────┐
                            ▼               ▼                  ▼
                     [Flask MJPEG]    [Detector]         [RingBuffer]
                                       │                       │
                                       ▼                       │
                                  [EventBus] ─────────────────▶│
                                       │                       │
                                       ▼                       ▼
                                  [pyserial tx]           [ffmpeg → MP4]
                                       │                       │
                                       ▼                       ▼
                                 /dev/ttyUSB0           data/clips/N.mp4
                                       │
                                       │ ◀──── [pyserial rx] ◀── (evt:rfid, evt:gate, ...)
                                       ▼                              │
                              ┌─────────────┐                          ▼
                              │ ESP32 UART0 │                    [SQLite events]
                              └─────┬───────┘
                                    ▼
                              [uart_link_task]
                                    │
                                    ▼
                              [event_q] ◀─── [rfid_task] ◀─── [RC522]
                                    │   ◀─── [sensor_task] ◀── [HC-SR04]
                                    │   ◀─── [timers]
                                    ▼
                              [gate_fsm_task]
                                    │
                              ┌─────┼────────┬────────┬────────┐
                              ▼     ▼        ▼        ▼        ▼
                          [Servo] [LCD]  [Buzzer]  [LED]  [outbound_q]
                                                              │
                                                              ▼
                                                       [Serial.write JSON\n]
```

## 3.3. Thiết kế thuật toán điều khiển

Phần này trình bày các thuật toán cốt lõi của bộ điều khiển cổng AFC: xử lý RFID, đọc QR, nhận dạng khuôn mặt, điều khiển cánh chắn (FSM) và chống gian lận. Mỗi thuật toán đi kèm phân tích lý thuyết và lưu đồ.

### 3.3.1. Thuật toán điều khiển tổng thể

Lưu đồ tổng thể của bộ điều khiển (Hình 3.4):

```
START → boot system
   │
   ▼
[Pi 5: cap + detect + flask + rx + tx + heartbeat ready]
[ESP32: 4 FreeRTOS tasks + 5 timers ready, emit evt:boot]
   │
   ▼
[Wait: tín hiệu từ một trong 3 nguồn]
   │
   ┌─── Face detection ───┐
   │                       │
   │  ┌── QR detection ──┐ │
   │  │                  │ │
   │  │ ┌─── RFID ───┐   │ │
   │  │ │            │   │ │
   │  │ ▼            │   │ │
   │  │ ESP32 check  │   │ │
   │  │ allowlist    │   │ │
   │  │ │            │   │ │
   │  │ ▼ granted    │   │ │
   │  │ Push event   │   │ │
   │  │ to event_q   │   │ │
   │  │ │            │   │ │
   │  │ ▼            │   │ │
   │  │ Gate FSM ────────────────┐
   │  │ IDLE → OPENING            │
   │  │   → OPEN_WAIT             │
   │  │   → (waiting passage)     │
   │  │                           │
   ▼  ▼  ▼                        │
[Pi 5: matcher.match + debouncer + INSERT event] │
   │                              │
   ▼                              │
[uart.send_cmd("open", ...)]      │
   │                              │
   ▼                              │
[ESP32 uart_link parse,           │
 push EV_CMD_OPEN to event_q] ────┤
                                  ▼
                         [Gate FSM proceeds]
                                  │
                                  ▼
                       [HC-SR04 passage detected?]
                                  │ Yes
                                  ▼
                       [evt:person_passed →
                        Gate FSM → CLOSING → IDLE]
                                  │
                                  ▼
                                LOOP
```

**Hình 3.4.** *Lưu đồ thuật toán điều khiển tổng thể.*

### 3.3.2. Thuật toán xử lý RFID

**Cơ sở lý thuyết:** RFID 13.56 MHz dùng giao thức ISO/IEC 14443A để giao tiếp giữa đầu đọc (PCD – Proximity Coupling Device) và thẻ (PICC – Proximity IC Card). Mỗi thẻ có UID 4 byte hoặc 7 byte cố định khi sản xuất – không đổi được. Đề tài dùng UID làm khóa primary trong NVS allowlist, không đọc nội dung block (đơn giản hóa, không cần authentication key A/B).

**Lưu đồ thuật toán RFID** (Hình 3.5):

```
START (rfid_task, mỗi 50 ms)
   │
   ▼
[mfrc522.PICC_IsNewCardPresent()]
   │
   ├── False ──▶ vTaskDelay(50ms); LOOP
   │
   ▼ True
[mfrc522.PICC_ReadCardSerial()]
   │
   ├── Read fail ──▶ LOGW; LOOP
   │
   ▼ OK
[uid_hex = bytes_to_hex(uid.uidByte, uid.size)]
   │
   ▼
[allowlist_lookup(uid_hex, name_out) → hit?]
   │
   ├── True (granted) ──▶ [event.kind = EV_RFID_SCAN, i1=1, name=name_out]
   │                       Push to event_q
   │                       gate_fsm_task → OPENING (no ack needed)
   │
   └── False (denied) ──▶ [event.kind = EV_RFID_SCAN, i1=0]
                          Push to event_q
                          gate_fsm_task → emit evt:rfid denied + buzzer beep_err
                          (no state transition)
   │
   ▼
[PICC_HaltA() + PCD_StopCrypto1()]   ◀─ tránh đọc trùng khi thẻ giữ trên anten
   │
   ▼
[vTaskDelay(50ms); LOOP]
```

**Hình 3.5.** *Lưu đồ thuật toán xử lý RFID.*

### 3.3.3. Thuật toán đọc QR

**Cơ sở lý thuyết:** Mã QR (Quick Response code, do Denso Wave 1994) là mã matrix 2 chiều có thể chứa tới 4296 ký tự alphanumeric. Mỗi QR gồm 3 ô finder pattern ở 3 góc, các module dữ liệu được mã hóa Reed-Solomon error correction (4 mức: L 7%, M 15%, Q 25%, H 30%). Đề tài dùng thư viện `pyzbar` (wrapper Python của libzbar C library) để decode.

**Thông số:** trung bình 5 ms/khung trên Pi 5; tự xử lý xoay đến 360° và một mức biến dạng nhỏ – không cần preprocess.

**Lưu đồ thuật toán QR** (Hình 3.6):

```
START (detector thread, mỗi khung BGR)
   │
   ▼
[symbols = pyzbar.decode(bgr_frame)]
   │
   ├── Empty? ──▶ Tiếp tục face detection branch
   │
   ▼ Có
For each symbol in symbols:
   │
   ▼
[token = symbol.data.decode('utf-8', errors='replace')]
   │
   ▼
[user_id = matcher.lookup_qr(token)]
   │
   ├── None (token không tồn tại hoặc đã revoked) ──▶ Bỏ qua (no spam log)
   │
   ▼ user_id found
[AuthEvent(method='qr', user_id=..., granted=True)]
   │
   ▼
[Debouncer.should_emit?]
   │
   ├── False (đã grant user này trong < 5s) ──▶ Drop
   │
   ▼ True
[INSERT events(method='qr', user_id=..., granted=1)]
   │
   ▼
[uart.send_cmd('open', {user: name, reason: 'qr'})]
   │
   ▼
[recorder.trigger(event_id)]
   │
   ▼
END (next symbol or next frame)
```

**Hình 3.6.** *Lưu đồ thuật toán quét mã QR.*

QR token trong đề tài đơn giản: 16 byte ngẫu nhiên `secrets.token_hex(16)` = chuỗi 32 ký tự hex. Trong production, sẽ cần kèm HMAC + timestamp + TTL để chống tấn công replay (xem Hướng phát triển).

### 3.3.4. Thuật toán nhận dạng khuôn mặt

**Cơ sở lý thuyết:**

Bài toán nhận dạng khuôn mặt gồm 2 bước:

1. **Phát hiện (face detection):** xác định bbox vị trí khuôn mặt trong khung.
2. **Trích xuất embedding + so khớp (recognition):** chuyển ROI khuôn mặt thành vector số chiều cố định, so sánh với CSDL embedding đã lưu.

Đề tài dùng:
- **Phát hiện:** MediaPipe Face Detection (Google) – ~10 ms/khung trên Pi 5, sử dụng mô hình BlazeFace.
- **Embedding:** `face_recognition` (Adam Geitgey) – wrapper Python của dlib, dùng model `dlib_face_recognition_resnet_model_v1` ResNet-34 đã huấn luyện trên ~3 triệu khuôn mặt – đầu ra vector 128 chiều float32.
- **So khớp:** Euclidean distance trên 128-dim, nearest neighbor.

**Công thức Euclidean distance:**

$$ d(\mathbf{u}, \mathbf{v}) = \sqrt{\sum_{i=1}^{128} (u_i - v_i)^2} $$

Trong code: `numpy.linalg.norm(probe - enc)` – tính trên CPU Pi 5 với 200 vector mất ~1 ms (vectorized).

**Multi-sample matching:**

Mỗi user có 3–5 mẫu chụp ở các góc/biểu cảm khác nhau khi enroll. Khi match:

```python
def match_face(self, probe):
    user_dists = {}
    for user_id, enc in self._faces:
        d = np.linalg.norm(probe - enc)
        if d < user_dists.get(user_id, float('inf')):
            user_dists[user_id] = d
    best_user = min(user_dists, key=user_dists.get) if user_dists else None
    best_dist = user_dists.get(best_user, float('inf'))
    return best_user, best_dist
```

**Ngưỡng quyết định:**

| Khoảng cách | Quyết định |
|---|---|
| d < 0.55 | Grant (cho qua) |
| 0.55 ≤ d ≤ 0.65 | Uncertain (lặng lẽ bỏ qua, chờ khung tốt hơn) |
| d > 0.65 | Stranger (ghi sự kiện granted=0) |

Ngưỡng 0.55 chặt hơn mặc định 0.6 của face_recognition – vì hệ thống demo có base rate thấp (ít người), cần giảm false positive.

**Lưu đồ thuật toán nhận dạng khuôn mặt** (Hình 3.7):

```
START (detector thread, mỗi khung BGR)
   │
   ▼
[Convert BGR → RGB]              (cv2.cvtColor)
   │
   ▼
[MediaPipe Face Detection]
   │
   ├── Không có khuôn mặt ──▶ Return (next frame)
   │
   ▼
[Chọn bbox có score cao nhất]
   │
   ▼
[Pad bbox 20% mỗi chiều, crop ROI]
   │
   ▼
[face_recognition.face_encodings(roi, num_jitters=1)]
   │
   ├── Empty list ──▶ Return
   │
   ▼
[probe = encodings[0].astype('float32')]
   │
   ▼
[matcher.match_face(probe) → (user_id, distance)]
   │
   ├── d < 0.55 ──▶ [granted=True, method='face']
   │                 │
   │                 ▼
   │              [Debouncer.should_emit?]
   │                 │
   │                 ├── False ─▶ Drop (cooldown)
   │                 │
   │                 ▼ True
   │              [INSERT events; uart.send_cmd('open',...)]
   │              [recorder.trigger]
   │                 │
   │                 ▼
   │              END
   │
   ├── 0.55 ≤ d ≤ 0.65 ──▶ Drop silently (uncertain)
   │
   ▼ d > 0.65
[granted=False, user_id=None]
   │
   ▼
[Debouncer.should_emit_stranger?]
   │
   ├── False ──▶ END (cooldown 30s)
   │
   ▼ True
[INSERT events (stranger); recorder.trigger]
   │
   ▼
END
```

**Hình 3.7.** *Lưu đồ thuật toán nhận dạng khuôn mặt.*

### 3.3.5. Quy trình enroll khuôn mặt

CLI `python -m smart_gate.cli enroll --name alice --samples 5`:

1. Mở webcam qua cv2.
2. Hiển thị live preview với bbox khuôn mặt (MediaPipe).
3. Hướng dẫn người dùng nhấn SPACE để chụp 1 mẫu (5 mẫu ở các góc/biểu cảm).
4. Với mỗi mẫu: tính embedding 128-dim, INSERT vào `face_encodings`.
5. Phát signal SIGUSR1 đến daemon → daemon reload matcher.
6. Sinh QR token (16 byte ngẫu nhiên = 32 ký tự hex), INSERT vào `qr_tokens`, ghi PNG vào `data/qr/<name>.png` bằng thư viện `qrcode`.

**So sánh các tùy chọn training:**

| Tùy chọn | Cách làm | Cần GPU |
|---|---|---|
| Google Colab + FaceNet/ArcFace finetune | Train end-to-end | Có |
| OpenCV LBPHRecognizer | Train trên grayscale LBP histogram | Không |
| face_recognition (đã chọn) | Pretrained dlib ResNet-34, chỉ tạo embedding | Không |

Với base rate < 50 người, pretrained embedding đã đủ. Finetune chỉ cần khi dataset người Việt khác biệt rõ với dataset gốc hoặc cần accuracy > 99%.

### 3.3.6. Thuật toán điều khiển cánh chắn (Gate FSM)

**Cơ sở lý thuyết:** Máy trạng thái hữu hạn (Finite State Machine – FSM) gồm 5 trạng thái thể hiện đầy đủ lifecycle của một chu kỳ mở-đóng cổng:

- `IDLE`: trạng thái nghỉ, chờ kích hoạt.
- `OPENING`: cánh chắn đang mở (Servo write 100°, chờ 300 ms).
- `OPEN_WAIT`: cánh chắn mở, chờ hành khách đi qua (timer 10 s).
- `TIMEOUT_WARN`: hết 10 s không thấy đi qua → buzzer cảnh báo (timer 5 s).
- `CLOSING`: cánh chắn đang đóng (Servo write 10°, chờ 300 ms).

**Sơ đồ trạng thái** (Hình 3.8):

```
        ┌──── cmd:open hoặc RFID granted ────┐
        │                                     │
        ▼                                     │
   ┌───────┐  300 ms timer  ┌────────────┐    │
   │ IDLE  │ ──────────────▶│  OPENING   │    │
   └───┬───┘ (phát evt:gate │ (servo PWM │    │
       │  state=opening,    │  → 100°)   │    │
       │  LCD show name,    │            │    │
       │  buzzer beep_ok)   └─────┬──────┘    │
       │                          │           │
       │                          ▼ 300ms     │
       │                  ┌────────────────┐  │
       │                  │  OPEN_WAIT     │  │
       │                  │  10s passage   │  │
       │                  │  timer         │  │
       │                  └─┬────────┬─────┘  │
       │              passage   │     │ 10s   │
       │              detected  │     │ timeout
       │                        │     ▼       │
       │            ┌───────────┘  ┌────────────────┐
       │            │              │ TIMEOUT_WARN   │
       │            │              │ (buzzer warn,  │
       │            │              │  5s give-up)   │
       │            │              └─┬──────┬───────┘
       │            │                │      │
       │            │       passage  │      │ 5s
       │            │       detected │      ▼
       │            ▼                │  ┌────────┐
       │      ┌──────────┐           │  │CLOSING │
       │      │ CLOSING  │ ◀─────────┘  │        │
       │      │ servo PWM│              │        │
       │      │ → 10°    │              │        │
       │      └────┬─────┘              │        │
       │           │ 300ms              │        │
       └───────────┘ ──────────────────▶ IDLE
                                                 
   cmd:close (admin override) ─────────────▶ CLOSING
   cmd:open in OPEN_WAIT ──────▶ reset 10s passage timer (admin hold)
```

**Hình 3.8.** *Máy trạng thái cổng (Gate FSM) trên ESP32.*

**Đặc biệt:**
- SG90 không có feedback vị trí → "Servo đến đích" được giả định sau timer 300 ms (SG90 ≈ 300°/s × 90° ≈ 300 ms).
- `cmd:open` lặp lại trong `OPEN_WAIT` reset bộ đếm 10 s – admin có thể giữ cổng mở cho VIP.
- `cmd:open` trong `OPENING`/`CLOSING` → ack `{ok:false, err:"busy"}`.
- `EV_RFID_SCAN` với i1=0 (denied) trong bất kỳ state → buzzer beep_err + evt:rfid denied, không transition.

### 3.3.7. Thuật toán chống gian lận

Đề tài Smart Gate chỉ triển khai chống gian lận **mức cơ bản** (Hình 3.9):

```
START
   │
   ▼
[Sự kiện xác thực mới đến debouncer]
   │
   ▼
┌─────────────────────────────────┐
│ Kiểm tra cooldown:              │
│ - granted: per-user 5s cooldown │
│ - stranger: 30s global cooldown │
└──────────────┬──────────────────┘
   │
   ├── Trong cooldown ──▶ Drop event (chống spam giữ thẻ liên tục)
   │
   ▼ Past cooldown
[Cập nhật last_grant/last_stranger]
   │
   ▼
[Phát event vào downstream]
   │
   ▼
[ESP32 RC522 PICC_HaltA() + PCD_StopCrypto1()]
   (chỉ ESP32 side – tránh đọc trùng cùng 1 thẻ)
   │
   ▼
END
```

**Hình 3.9.** *Lưu đồ thuật toán chống gian lận cơ bản.*

Các kỹ thuật chống gian lận **chưa** triển khai (xem Hướng phát triển):
- Counting beam đếm tailgate (2 người đi sau 1 lần mở).
- YOLO person-counter qua camera.
- Anti-spoofing khuôn mặt (liveness, depth, texture analysis).
- HMAC + TTL cho QR token (chống replay).

### 3.3.8. Giao thức UART JSON Lines (Pi ↔ ESP32)

**Cấu trúc khung tin:** một bản tin = 1 dòng UTF-8 JSON kết thúc bằng `\n`, tối đa 512 byte.

```json
{"id": 42, "type": "cmd", "v": "open", "data": {"user": "alice", "reason": "face"}}
```

| Trường | Bắt buộc | Ý nghĩa |
|---|---|---|
| `id` | Khi cần ACK | Pi gán số nguyên tăng dần; ESP32 echo lại trong `ack` |
| `type` | Bắt buộc | `"cmd"` / `"evt"` / `"ack"` |
| `v` | Bắt buộc | Verb (động từ) |
| `data` | Tùy verb | Object payload |

Không có CRC (USB-CDC tự lo CRC ở mức USB). Không length-prefix (newline framing đủ). Parser lỗi → drop dòng, tiếp tục.

**Bảng 3.3. Bộ động từ lệnh (cmd) Pi → ESP32**

| Verb | data | ack data | Mục đích |
|---|---|---|---|
| `open` | `{user, reason}` | `{ok:true}` | Pi đã xác thực face/QR; ESP32 mở cổng |
| `close` | – | `{ok:true}` | Cưỡng bức đóng (admin override) |
| `add_uid` | `{uid, name}` | `{ok:true,total:N}` | Thêm UID vào allowlist |
| `remove_uid` | `{uid}` | `{ok:true}` hoặc `{ok:false,err:"not_found"}` | Xóa UID |
| `list_uids` | – | `{uids:[{uid,name},...]}` | Dump allowlist |
| `config` | `{close_timeout_s, servo_open_deg, servo_close_deg}` | `{ok:true}` | Cập nhật cấu hình |
| `status` | – | `{uptime_s, free_heap, gate, fw}` | Snapshot |
| `ping` | – | `{ok:true}` | Liveness probe (Pi gửi mỗi 5 s) |

**Bảng 3.4. Bộ động từ sự kiện (evt) ESP32 → Pi**

| Verb | data | Khi nào |
|---|---|---|
| `boot` | `{fw, free_heap, reset_reason}` | Một lần sau khi các task FreeRTOS sẵn sàng |
| `rfid` | `{uid, result, name?}` | Mỗi lần quét thẻ |
| `gate` | `{state}` | Mỗi chuyển trạng thái FSM |
| `person_passed` | `{distance_cm, ms}` | HC-SR04 phát hiện hành khách đã qua |
| `heartbeat` | `{uptime_s, free_heap, gate}` | Mỗi 10 s |
| `log` | `{lvl, tag, msg}` | Debug messages có rate-limit |

### 3.3.9. Cơ chế ACK và heartbeat

**ACK:** Pi gắn `id` tăng dần vào mỗi `cmd`. ESP32 hồi đáp `{"type":"ack", "id":<id>, "v":<verb>, "data":{...}}` trong < 100 ms. Pi giữ ack_event timer 2 s; quá thời gian → raise `LinkTimeout`.

**Heartbeat:** Pi gửi `cmd:ping` mỗi 5 s; ESP32 phát `evt:heartbeat` mỗi 10 s. Nếu Pi không nhận được message gì từ ESP32 trong 30 s → coi link là dead, đặt `link_alive = False`.

**Standalone resilience:** Khi Pi mất kết nối:
- ESP32 vẫn polling RC522 → xác thực thẻ NVS allowlist → kích FSM tự.
- LCD hiển thị `Welcome: <name>`, cánh chắn mở/đóng bình thường.
- HC-SR04 vẫn phát hiện hành khách đã qua → cổng đóng.
- ESP32 không panic vì thiếu heartbeat Pi.

Khi Pi quay lại:
- Pi nhận `evt:boot` từ ESP32 (nếu ESP32 đã reboot do brownout/lỗi khác).
- Pi gửi `cmd:config` để re-sync runtime params.
- Tiếp tục heartbeat ping mỗi 5 s.

### 3.3.10. Tổng hợp các thuật toán/cấu trúc dữ liệu

**Bảng 3.5. Tổng hợp 20 thuật toán/cấu trúc dữ liệu chính**

| # | Thuật toán | Triển khai | Vai trò |
|---|---|---|---|
| 1 | MediaPipe Face Detection | `mp.solutions.face_detection.FaceDetection` | Khoanh khuôn mặt |
| 2 | dlib face_recognition_model_v1 | `face_recognition.face_encodings` | Embedding 128-dim |
| 3 | Euclidean distance + nearest neighbor | `numpy.linalg.norm` + dict argmin | Match user |
| 4 | Multi-sample min-distance | for-loop trong matcher | Cải thiện accuracy |
| 5 | Threshold + uncertain band | `if d < 0.55: grant elif d > 0.65: stranger` | Giảm false positive |
| 6 | pyzbar libzbar wrapper | `pyzbar.decode(bgr)` | Decode QR |
| 7 | Debounce cooldown | `if now - last_grant[uid] < 5: skip` | Tránh trigger trùng |
| 8 | FrameHub fan-out | `threading.Condition.notify_all` | 3 consumers / 1 source |
| 9 | RingBuffer 5s | `collections.deque(maxlen=fps*5)` | Lưu khung pre-event |
| 10 | ffmpeg H.264 encode | `subprocess.run([...])` | MP4 clip 10s |
| 11 | JSON Lines framing | `json.dumps + "\n".encode("utf-8")` | UART protocol |
| 12 | UART exponential backoff | `1, 2, 5, 10, 30 s` | Robust port handling |
| 13 | HC-SR04 debounce 3-count | `below_count` / `above_count` | Lọc nhiễu |
| 14 | FreeRTOS xTimer one-shot | `xTimerCreate(..., pdFALSE, ...)` | Servo settle, timeout, warn |
| 15 | FreeRTOS xQueue | `xQueueCreate(16, sizeof(event_t))` | Inter-task event passing |
| 16 | TWDT watchdog | `esp_task_wdt_add(gate_fsm_task)` | Auto-reboot nếu FSM stall |
| 17 | NVS Preferences `_index` sidecar | Self-maintained JSON array | Enumerate allowlist |
| 18 | Rate-limited log | 1 evt:log/s per (lvl, tag) | Tránh flood UART |
| 19 | LEDC PWM 50 Hz Servo | `ledc_set_duty(channel0)` | Servo control |
| 20 | I2C 100 kHz LCD | `Wire.begin(SDA, SCL); lcd.begin()` | LCD HD44780 qua PCF8574 |

## 3.4. Thiết kế giao diện giám sát

Đề tài chọn **Flask** (Python micro-framework) chạy trên Pi 5 cho web admin LAN, không có web admin trên ESP32 (do Wi-Fi ESP32 đã tắt theo phương án thiết kế).

### 3.4.1. Sơ đồ chức năng giao diện

```
                    Browser (LAN, không có authentication)
                              ▲
                              │ HTTP/HTTPS
                              ▼
                    ┌──────────────────────┐
                    │  Werkzeug threaded   │
                    │  server :8080        │
                    │  (Flask 3.0.3)       │
                    └────────┬─────────────┘
                             │
        ┌────────────────────┼────────────────────┐
        ▼                    ▼                    ▼
┌──────────────┐    ┌──────────────┐    ┌──────────────┐
│  Routes:     │    │  Routes:     │    │  Routes:     │
│  /           │    │  /api/gate/  │    │  /events.json│
│  /stream     │    │  open|close  │    │  /clips/N.mp4│
│  /users      │    │  (manual     │    │  /healthz    │
│              │    │   override)  │    │              │
└──────┬───────┘    └──────┬───────┘    └──────┬───────┘
       │                   │                   │
       ▼                   ▼                   ▼
   FrameHub          UartClient          SQLite DB
   wait_jpeg()       send_cmd()          query events
```

**Hình 3.10.** *Sơ đồ chức năng giao diện giám sát Flask.*

### 3.4.2. Các route Flask

| URL | Phương thức | Chức năng |
|---|---|---|
| `/` | GET | `dashboard.html` – trang chính |
| `/stream.mjpeg` | GET | `multipart/x-mixed-replace` MJPEG generator từ FrameHub.wait_jpeg() |
| `/events.json?after_id=N` | GET | JSON list 50 sự kiện gần nhất (HTMX polling 2s) |
| `/users` | GET | Bảng user, số mẫu face, QR active |
| `/clips/<int:event_id>.mp4` | GET | `send_file()` từ data/clips/; 404 nếu clip_path NULL |
| `/api/gate/open` | POST | `uart.send_cmd("open", {user:"admin",reason:"manual"}, 2.0)` |
| `/api/gate/close` | POST | `uart.send_cmd("close", None, 2.0)` |
| `/healthz` | GET | `{uptime_s, link_alive, last_frame_ago_s, threads_ok}` |

Templates Jinja2 + HTMX (`/static/htmx.min.js` ~14 KB) polling `/events.json` mỗi 2 s. Pico.css (~10 KB) cho style baseline. Không SPA framework. Không auth (LAN-only).

### 3.4.3. Bố cục dashboard

```
┌────────────────────────────────┬──────────────────────────────┐
│   [HỌ TÊN SVTH]  –  [MSV]      │  Events (hx-trigger=every 2s)│
│   Smart Gate Dashboard          │  ┌─────┬──────┬────────┐    │
├────────────────────────────────┤  │ time│ user │ method │    │
│                                │  ├─────┼──────┼────────┤    │
│   <img src="/stream.mjpeg">    │  │ ... │  ... │  ...   │    │
│   (640×480 MJPEG live)         │  │ ... │  ... │  ...   │    │
│                                │  └─────┴──────┴────────┘    │
│   [ Open gate ] [ Close gate ] │                              │
│   Link: ● up   Frame: 0.2s ago │                              │
├────────────────────────────────┴──────────────────────────────┤
│   Footer: GVHD: [GVHD]  –  Lớp [LỚP]  –  Khoá [KHÓA]          │
└────────────────────────────────────────────────────────────────┘
```

**Hình 3.11.** *Bố cục dashboard giám sát.*

Dashboard hiển thị:
- Tên sinh viên + MSV ở header (theo yêu cầu trong template `cơ bản.docx`).
- MJPEG live preview 640×480.
- Bảng sự kiện gần nhất (cập nhật mỗi 2 s).
- Nút Open/Close gate (manual override).
- Thông tin link và frame age.

### 3.4.4. MJPEG stream generator

```python
def mjpeg_stream():
    while True:
        jpg = hub.wait_jpeg(timeout=2.0)
        if jpg is None:
            jpg = PLACEHOLDER_JPEG  # "Camera offline" ~3 KB
        yield (b"--FRAME\r\nContent-Type: image/jpeg\r\n"
               b"Content-Length: " + str(len(jpg)).encode() + b"\r\n\r\n"
               + jpg + b"\r\n")
```

Mỗi khung mới do FrameHub broadcast được serialize thẳng đến browser qua HTTP multipart. Browser native render qua `<img src="/stream.mjpeg">` – không cần JS player.

### 3.4.5. CLI quản trị

`python -m smart_gate.cli <subcommand>`:

| Subcommand | Chức năng |
|---|---|
| `enroll --name X --samples 5` | Capture 5 mẫu khuôn mặt + sinh QR + INSERT DB |
| `users list` | Bảng user, created_at, last_seen, #encodings, #qr active |
| `users delete --name X` | DELETE FROM users WHERE name=? (CASCADE) |
| `qr rotate --name X` | Revoke old + insert new token + rewrite PNG |
| `qr revoke --name X` | UPDATE qr_tokens SET revoked_at=now() |
| `events tail -n 20` | SELECT ... ORDER BY ts DESC LIMIT 20 |
| `db migrate` | Apply migrations idempotently |

CLI tách riêng tiến trình daemon → an toàn khi chạy đồng thời nhờ SQLite WAL + busy_timeout. Sau mỗi mutation, CLI gửi `SIGUSR1` đến PID daemon (`/run/smart-gate/pid`) để matcher reload.
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

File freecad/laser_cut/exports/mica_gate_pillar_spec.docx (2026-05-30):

# MICA GATE PILLAR — LASER CUT

Smart gate pillar enclosure (Pi 4 + ESP32 + sensors)

## Vật liệu & khổ tấm

Mica acrylic trong suốt, độ dày 5 mm. Khổ tấm: 1000 × 600 mm (1 tấm đủ 8 chi tiết, tổng diện tích cắt ~0.30 m²).

## Quy ước trên file

- Đường ĐỎ (RGB 255,0,0): CẮT THỦNG
- Đường ĐEN (RGB 0,0,0): KHẮC NÔNG (engrave ~0.2mm, không thủng)
- Stroke 0.3/0.5mm chỉ để hiển thị PDF — máy laser cắt theo đường tâm geometry.

## Danh sách 8 chi tiết
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

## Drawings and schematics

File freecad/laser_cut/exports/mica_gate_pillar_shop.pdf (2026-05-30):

# MICA GATE PILLAR — LASER CUT

Smart gate pillar enclosure (Pi 4 + ESP32 + sensors)

Vật liệu & khổ tấm

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

Quy ước trên file
- Đường ĐỎ (RGB 255,0,0): CẮT THỦNG
- Đường ĐEN (RGB 0,0,0): KHẮC NÔNG (engrave, sâu ~0.2mm, không cắt thủng)
- Stroke 0.3/0.5mm chỉ để hiển thị PDF — máy laser cắt theo đường tâm geometry, không theo độ dày stroke.

Danh sách 8 chi tiết

# | Mảnh | Kích thước | Ghi chú

1 | FRONT | 150 × 228 mm | Mặt trước (không cutout)
2 | BACK | 150 × 300 mm | Mặt sau, lỗ adapter Ø10mm + 6 lỗ M3
3 | LEFT | 240 × 300 mm | Pentagon, mặt tháo, 4 lỗ M3 corner + 4 lỗ M3 PCB
4 | RIGHT | 240 × 300 mm | Pentagon, khe arm 20×120mm + HC-SR04 cluster
5 | TOP | 150 × 168 mm | Mặt trên, LCD 98×40 + camera + USB pass-through 20×12
6 | SLOPE | 150 × 102 mm | Mặt vát 45° (trống, RFID đọc xuyên qua)
7 | BOTTOM | 150 × 240 mm | Mặt đáy, 5 khe thông gió 30×3mm
8 | ARM | 115 × 15 mm | Cần chắn, 3 sọc engrave 20×5mm (sơn ĐỎ sau khi cắt)

Dung sai
±0.2 mm cho lỗ và mép. Đường cắt cùng tấm cách nhau ≥5 mm để tránh vỡ mica.

Lưu ý ARM
Sau khi cắt, sơn ĐỎ vào 3 vạch khắc trên thanh ARM để tạo sọc đỏ-trắng giống barrier thật. 2 lỗ Ø2.2mm gần đầu là điểm bắt vít M2 vào servo horn.

Trang sau: layout cắt (8 mảnh trên khổ 1000 × 600 mm).

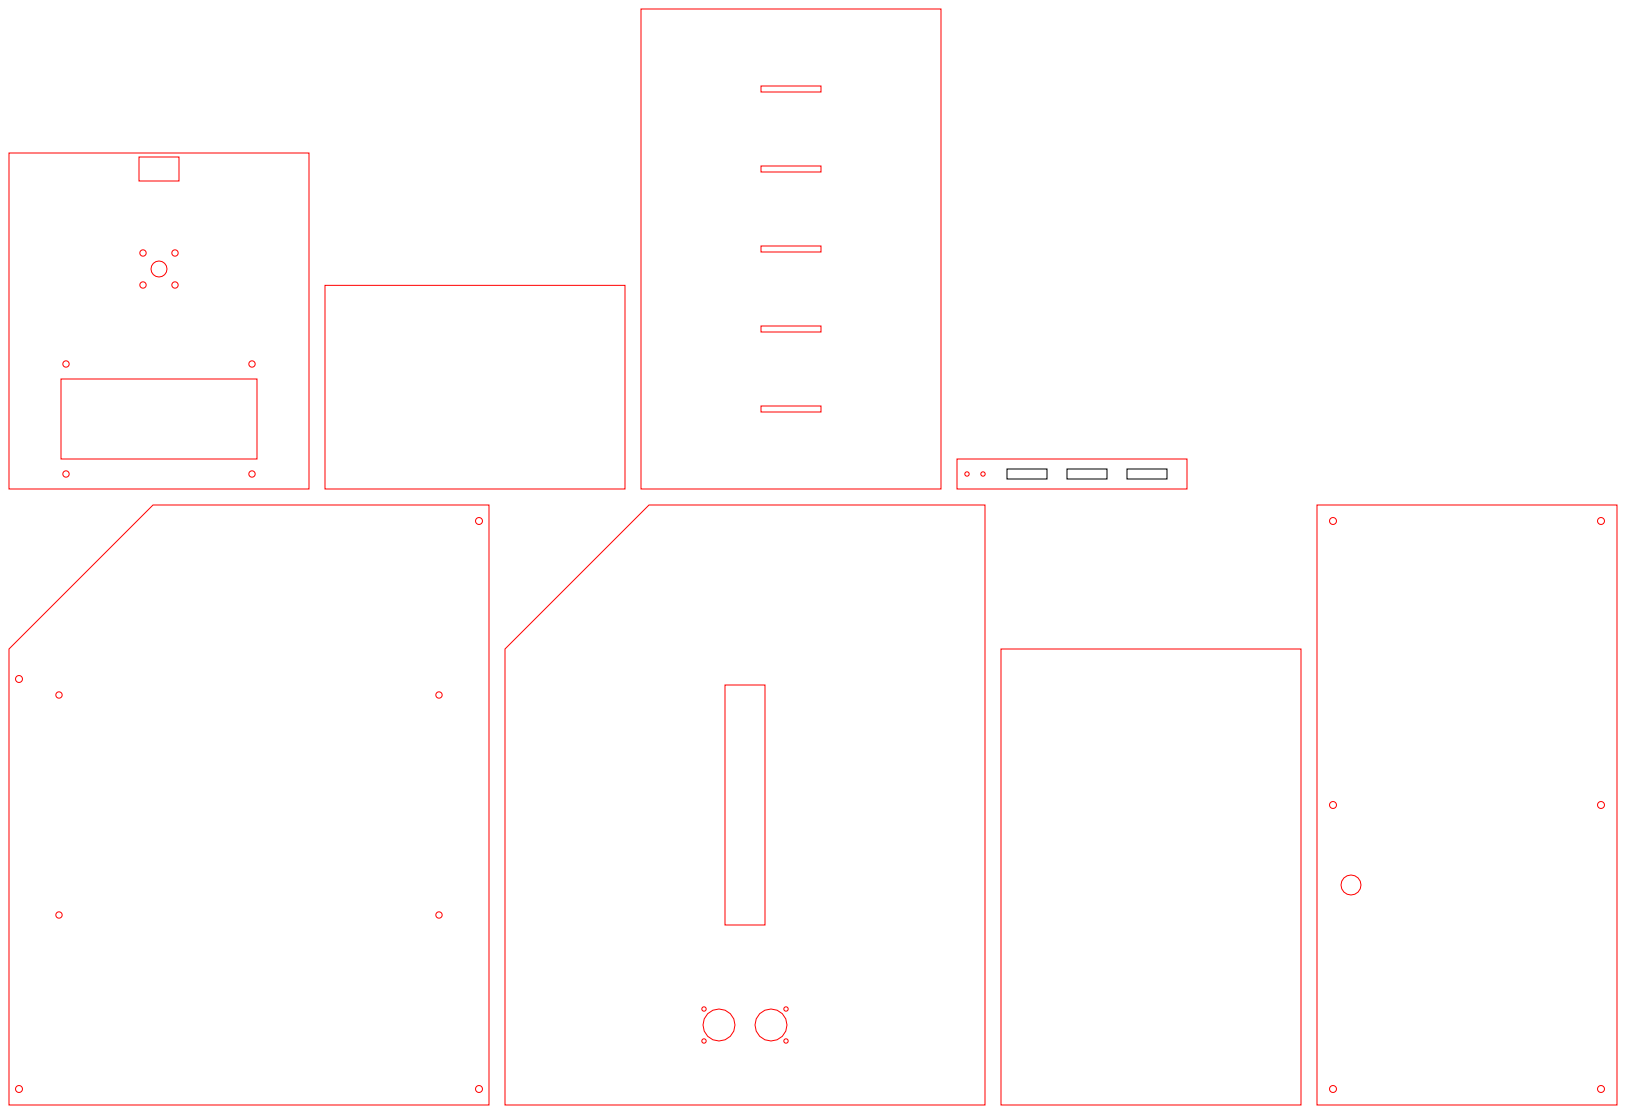
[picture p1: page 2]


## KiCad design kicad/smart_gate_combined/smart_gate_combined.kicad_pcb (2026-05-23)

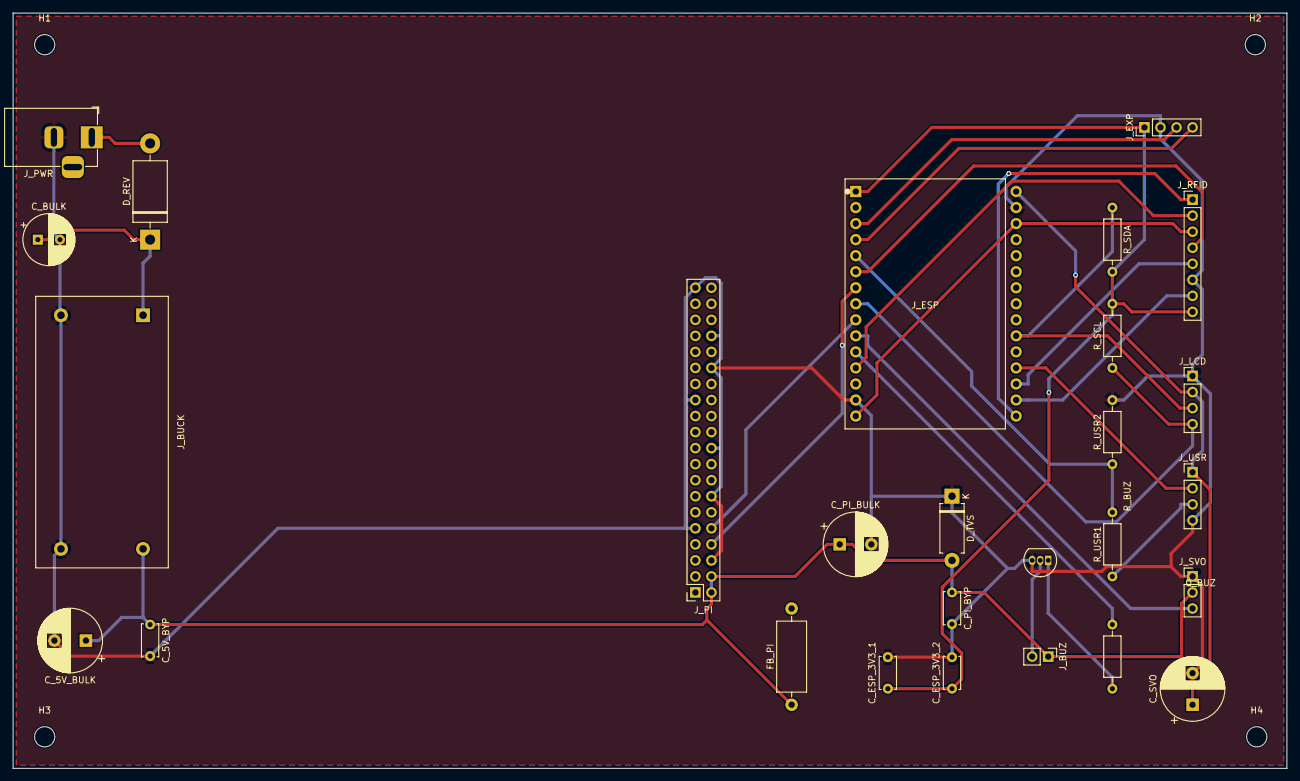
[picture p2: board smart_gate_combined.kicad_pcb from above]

Board: 2 copper layers, 201.7 x 119.6 mm, 31 parts (0 on the bottom side), 24 nets.

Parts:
C_5V_BULK: 1000uF/10V; CP_Radial_D10.0mm_P5.00mm
C_5V_BYP: 100nF; C_Disc_D5.0mm_W2.5mm_P5.00mm
C_BULK: 100uF/25V; CP_Radial_D8.0mm_P3.50mm
C_ESP_3V3_1: 100nF; C_Disc_D5.0mm_W2.5mm_P5.00mm
C_ESP_3V3_2: 10uF; C_Disc_D5.0mm_W2.5mm_P5.00mm
C_PI_BULK: 1000uF/10V; CP_Radial_D10.0mm_P5.00mm
C_PI_BYP: 100nF; C_Disc_D5.0mm_W2.5mm_P5.00mm
C_SVO: 470uF/16V; CP_Radial_D10.0mm_P5.00mm
D_REV: 1N5817; D_DO-201AD_P15.24mm_Horizontal
D_TVS: SMAJ5.0A; D_DO-15_P10.16mm_Horizontal
FB_PI: FB_600R_3A; L_Axial_L11.0mm_D4.5mm_P15.24mm_Horizontal_Fastron_MECC
H1, H2, H3, H4: MountingHole_3.2mm_M3
J_BUCK: LM2596_Mini_Buck
J_BUZ: Buzzer_Active; PinHeader_1x02_P2.54mm_Vertical
J_ESP: ESP32_DevKit_V1; ESP32_DevKit_V1_30pin
J_EXP: Expansion; PinHeader_1x04_P2.54mm_Vertical
J_LCD: LCD_20x4_I2C; PinHeader_1x04_P2.54mm_Vertical
J_PI: Pi_5_GPIO_2x20; PinSocket_2x20_P2.54mm_Vertical
J_PWR: 12V_IN; BarrelJack_Horizontal
J_RFID: RC522; PinHeader_1x08_P2.54mm_Vertical
J_SVO: Servo_SG90; PinHeader_1x03_P2.54mm_Vertical
J_USR: HC-SR04; PinHeader_1x04_P2.54mm_Vertical
Q_BUZ: 2N3904; TO-92_Inline
R_BUZ: 1k; R_Axial_DIN0207_L6.3mm_D2.5mm_P10.16mm_Horizontal
R_SCL: 4.7k; R_Axial_DIN0207_L6.3mm_D2.5mm_P10.16mm_Horizontal
R_SDA: 4.7k; R_Axial_DIN0207_L6.3mm_D2.5mm_P10.16mm_Horizontal
R_USR1: 1k; R_Axial_DIN0207_L6.3mm_D2.5mm_P10.16mm_Horizontal
R_USR2: 2k; R_Axial_DIN0207_L6.3mm_D2.5mm_P10.16mm_Horizontal

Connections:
+3V3: C_ESP_3V3_1.1, C_ESP_3V3_2.1, J_ESP.1, J_EXP.1, J_RFID.8, R_SCL.2, R_SDA.2
+5V: C_5V_BULK.1, C_5V_BYP.1, C_PI_BULK.1, C_PI_BYP.1, C_SVO.1, D_TVS.2, FB_PI.1, J_BUCK.4, J_BUZ.1, J_ESP.2, J_LCD.2, J_PI.2, J_PI.4, J_SVO.2, J_USR.1
+12V: C_BULK.1, D_REV.1, J_BUCK.1
BUZ_COLLECTOR: J_BUZ.2, Q_BUZ.2
BUZ_DRIVE: J_ESP.21, R_BUZ.1
ESP_TX_PI_RX: J_ESP.17, J_PI.10
GND: C_5V_BULK.2, C_5V_BYP.2, C_BULK.2, C_ESP_3V3_1.2, C_ESP_3V3_2.2, C_PI_BULK.2, C_PI_BYP.2, C_SVO.2, D_TVS.1, J_BUCK.2, J_BUCK.3, J_ESP.4, J_ESP.27, J_EXP.2, J_LCD.1, J_PI.6, J_PI.9, J_PI.14, J_PI.20, J_PI.25, J_PI.30, J_PI.34, J_PI.39, J_PWR.2, J_RFID.6, J_SVO.1, J_USR.4, Q_BUZ.3, R_USR2.2
HCSR_ECHO_3V3: J_ESP.9, R_USR1.2, R_USR2.1
HCSR_ECHO_5V: J_USR.3, R_USR1.1
HCSR_TRIG: J_ESP.24, J_USR.2
I2C_SCL: J_ESP.15, J_LCD.4, R_SCL.1
I2C_SDA: J_ESP.20, J_LCD.3, R_SDA.1
IO36: J_ESP.5, J_EXP.3
IO39: J_ESP.7, J_EXP.4
unnamed: D_REV.2, J_PWR.1
unnamed: Q_BUZ.1, R_BUZ.2
PI_TX_ESP_RX: J_ESP.13, J_PI.8
RC522_CS: J_ESP.30, J_RFID.1
RC522_IRQ: J_ESP.26, J_RFID.5
RC522_MISO: J_ESP.11, J_RFID.4
RC522_MOSI: J_ESP.6, J_ESP.29, J_RFID.3
RC522_RST: J_ESP.28, J_RFID.7
RC522_SCK: J_ESP.23, J_RFID.2
SERVO_PWM: J_ESP.19, J_SVO.3

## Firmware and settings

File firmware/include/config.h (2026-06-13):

#pragma once

// === Pin assignments (mirror architecture spec §5) ===
#define PIN_LED_STATUS   2
#define PIN_RC522_CS     5
#define PIN_RC522_SCK    18
#define PIN_RC522_MISO   19
#define PIN_RC522_MOSI   23
#define PIN_RC522_RST    17
#define PIN_RC522_IRQ    16
#define PIN_LCD_SDA      21
#define PIN_LCD_SCL      22
#define PIN_SR04_TRIG    27
#define PIN_SR04_ECHO    26
#define PIN_SERVO        13
#define PIN_BUZZER       14

// Pi link runs on ESP32 UART1 routed via the GPIO matrix (decision #26, 2026-05-23).
// Pi pin 8 (BCM14, TX0) → ESP32 GPIO 32 (UART1 RX);
// Pi pin 10 (BCM15, RX0) ← ESP32 GPIO 25 (UART1 TX).
// UART0 (GPIO 1/3, USB-CDC) stays reserved for `pio device monitor` debug + `esptool.py` flashing.
#define PIN_PI_UART_RX   32
#define PIN_PI_UART_TX   25

// === Timings (ms) ===
#define DEFAULT_OPEN_REACHED_MS    300
#define DEFAULT_CLOSE_REACHED_MS   300
#define DEFAULT_PASSAGE_TIMEOUT_MS 10000
#define DEFAULT_WARN_GIVEUP_MS     5000
#define HEARTBEAT_INTERVAL_MS      10000
#define RFID_POLL_INTERVAL_MS      50
#define SENSOR_POLL_INTERVAL_MS    50
#define SENSOR_DEBOUNCE_COUNT      3
#define SENSOR_TRIGGER_CM          25

// === Servo angles ===
#define DEFAULT_SERVO_OPEN_DEG     100
#define DEFAULT_SERVO_CLOSE_DEG    10
// Physical safe range for SG90 horn vs enclosure — protects against a bad
// cmd:config (e.g. servo_open_deg=180) driving the horn into the wall and
// stalling the motor at ~700 mA until brown-out.
#define SERVO_MIN_PHYS_DEG         5
#define SERVO_MAX_PHYS_DEG         110
// Expected servo travel time end-to-end. Used both for the async detach timer
// margin and as the base period for the stall watchdog (2× this value).
// Kept aligned with DEFAULT_OPEN_REACHED_MS / DEFAULT_CLOSE_REACHED_MS so the
// reached-event and stall windows stay consistent.
#define SERVO_EXPECTED_TRAVEL_MS   DEFAULT_OPEN_REACHED_MS

// === LCD ===
#define LCD_I2C_ADDR              0x27
#define LCD_COLS                  20
#define LCD_ROWS                  4

// === NVS ===
#define NVS_NS_ALLOWLIST          "allowlist"
#define NVS_NS_CONFIG             "config"
#define NVS_NS_GATE_STATE         "gate_state"
#define NVS_INDEX_KEY             "_index"
#define ALLOWLIST_MAX_ENTRIES     100

// === Brown-out recovery ===
// Hold servo at 90° neutral for this long before falling through to enter_idle(),
// giving any person in the doorway time to step clear.
#define RECOVERY_HOLD_MS          5000
#define RECOVERY_NEUTRAL_DEG      90

// === UART / JSON ===
#define UART_BAUD                 115200
#define UART_LINE_MAX             512
#define JSON_DOC_CAPACITY         768
#define EVENT_QUEUE_LEN           16
#define OUTBOUND_QUEUE_LEN        16

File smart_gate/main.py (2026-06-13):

"""Daemon orchestrator: start threads, manage lifecycle, signals."""
from __future__ import annotations

import argparse
import logging
import os
import queue
import signal
import sys
import threading
import time
from logging.handlers import RotatingFileHandler
from pathlib import Path

from smart_gate.config import load_config
from smart_gate.data.db import Database
from smart_gate.data.esp_log_writer import EspLogWriter
from smart_gate.recognition.matcher import Matcher
from smart_gate.recognition import detector as detector_mod
from smart_gate.recognition.detector import AuthEvent, CheckInEvent
from smart_gate.recognition.overlay import OverlayState
from smart_gate.recognition.auto_enroll_pair import (
    AutoEnrollPairState,
    EnrollCandidate,
)
from smart_gate.recognition.cooldown import UserCooldown
from smart_gate.link.gate_state import GateTracker
from smart_gate.link.peripheral_status import PeripheralTracker
from smart_gate.video.fps_counter import FpsCounter
from smart_gate.video.framehub import FrameHub
from smart_gate.video.recorder import RingBuffer, RecordingTrigger, run_recorder, cleanup_pass
from smart_gate.video import capture as capture_mod
from smart_gate.link.uart_client import UartClient, EspEvent, LinkDown, LinkTimeout
from smart_gate.link.esp_log_bus import EspLogBus
from smart_gate.web.app import create_app

log = logging.getLogger("smart_gate.main")

# Most-recent shutdown Event, exposed for tests / external triggers.
_current_shutdown: threading.Event | None = None


def _cap_rfid_fields(d: dict) -> tuple[str, str]:
    """Truncate ESP-supplied name/uid to firmware-buffer-sized limits.

    Firmware uses e.name[32] and e.uid[24]; a misbehaving ESP could in
    principle send much longer strings. Bound them at the protocol
    boundary so log lines, SQL binds, and dashboard renders are all safe.
    """
    name = (d.get("name") or "")[:32]
    uid  = (d.get("uid")  or "")[:24]
    return name, uid


def main(argv=None) -> int:
    global _current_shutdown
    # Cap per-thread stack from glibc's 8 MB default to 256 KB. Werkzeug's
    # threaded server spawns one thread per request; a leaked/long-lived
    # thread otherwise reserves 8 MB of VM each, making RSS balloon under
    # tab churn. Must be set BEFORE any thread starts.
    threading.stack_size(256 * 1024)

    p = argparse.ArgumentParser(prog="smart_gate")
    p.add_argument("--config", default="/etc/smart-gate/config.toml")
    args = p.parse_args(argv)

    cfg = load_config(args.config)
    _setup_logging(cfg)
    _write_pidfile()

    data_dir = Path(cfg.paths.data_dir)
    data_dir.mkdir(parents=True, exist_ok=True)
    (data_dir / "clips").mkdir(exist_ok=True)
    (data_dir / "qr").mkdir(exist_ok=True)

    db = Database(data_dir / "smart_gate.db")
    db.migrate()
    matcher = Matcher(db)

    hub = FrameHub()
    overlay = OverlayState(stale_after_s=2.0)
    # 1-of-3 channel cooldowns + RFID-only auto-enroll pairing.
    # Each auth channel now fires its own CheckInEvent independently; the
    # per-user cooldown suppresses duplicate fires while the same user
    # stays in frame / keeps the card on the reader.
    face_cooldown = UserCooldown(cfg.recognition.face_cooldown_s)
    qr_cooldown = UserCooldown(cfg.recognition.qr_cooldown_s)
    auto_enroll_state = AutoEnrollPairState(
        ttl_s=cfg.recognition.autoenroll_ttl_s)
    gate_tracker = GateTracker()
    peripherals = PeripheralTracker()
    cap_fps = FpsCounter(window_s=5.0)
    det_fps = FpsCounter(window_s=5.0)
    esp_log_bus = EspLogBus()
    esp_log_writer = EspLogWriter(db)
    esp_log_writer.start()
    ring = RingBuffer(fps=cfg.video.fps, pre_seconds=cfg.recorder.pre_seconds)
    bus: queue.Queue = queue.Queue()
    trig_queue: queue.Queue = queue.Queue(maxsize=5)
    shutdown = threading.Event()
    reload_event = threading.Event()
    _current_shutdown = shutdown

    _install_signal_handlers(shutdown, reload_event)

    uart = UartClient(cfg.link.port, cfg.link.baud, bus, shutdown,
                      ping_interval_s=cfg.link.ping_interval_s,
                      heartbeat_timeout_s=cfg.link.heartbeat_timeout_s)
    uart.start()

    threads = [
        threading.Thread(target=capture_mod.run_capture, name="cap",
                         args=(cfg, hub, ring, shutdown),
                         kwargs={"fps_counter": cap_fps},
                         daemon=True),
        threading.Thread(target=detector_mod.run_detector, name="detect",
                         args=(cfg, hub, matcher, bus, shutdown),
                         kwargs={"overlay": overlay,
                                 "face_cooldown": face_cooldown,
                                 "qr_cooldown": qr_cooldown,
                                 "auto_enroll_state": auto_enroll_state,
                                 "fps_counter": det_fps},
                         daemon=True),
        threading.Thread(target=run_recorder, name="rec",
                         args=(hub, ring, trig_queue, db, data_dir, cfg, shutdown),
                         daemon=True),
        threading.Thread(target=_consume_bus, name="bus-consumer",
                         args=(bus, db, matcher, uart, trig_queue, cfg, shutdown,
                               reload_event),
                         kwargs={"auto_enroll_state": auto_enroll_state,
                                 "gate_tracker": gate_tracker,
                                 "esp_log_bus": esp_log_bus,
                                 "esp_log_writer": esp_log_writer,
                                 "peripherals": peripherals},
                         daemon=True),
        threading.Thread(target=_run_web, name="flask",
                         args=(cfg, db, hub, uart, data_dir, shutdown),
                         kwargs={"matcher": matcher, "overlay": overlay,
                                 "reload_event": reload_event,
                                 "gate_tracker": gate_tracker,
                                 "cap_fps": cap_fps, "det_fps": det_fps,
                                 "esp_log_bus": esp_log_bus,
                                 "peripherals": peripherals},
                         daemon=True),
        threading.Thread(target=_cleanup_loop, name="cleanup",
                         args=(cfg, db, data_dir, shutdown), daemon=True),
        threading.Thread(target=_watchdog, name="watchdog",
                         args=(threading.enumerate, shutdown), daemon=True),
    ]
    for t in threads:
        t.start()

    log.info("smart_gate started (pid %d)", os.getpid())
    shutdown.wait()
    log.info("shutdown requested")
    for t in threads:
        t.join(timeout=15)
    uart.join(timeout=5)
    # Flush any tail of pending ESP log rows before exit.
    esp_log_writer.stop(timeout=2.0)
    log.info("smart_gate exited cleanly")
    return 0


def _setup_logging(cfg) -> None:
    Path(cfg.paths.log_dir).mkdir(parents=True, exist_ok=True)
    fmt = logging.Formatter(
        "%(asctime)s %(levelname)s [%(threadName)s] %(name)s: %(message)s"
    )
    level = logging.DEBUG if os.environ.get("SMART_GATE_DEBUG") else \
            getattr(logging, cfg.logging.level.upper(), logging.INFO)
    root = logging.getLogger()
    root.setLevel(level)
    fh = RotatingFileHandler(
        Path(cfg.paths.log_dir) / "app.log",
        maxBytes=cfg.logging.rotate_mb * 1024 * 1024,
        backupCount=cfg.logging.backup_count,
    )
    fh.setFormatter(fmt)
    sh = logging.StreamHandler(sys.stdout)
    sh.setFormatter(fmt)
    root.handlers = [fh, sh]


def _install_signal_handlers(shutdown: threading.Event,
                             reload_event: threading.Event) -> None:
    """Install SIGTERM/SIGINT/SIGUSR1 handlers. No-op when called from a
    non-main thread (e.g. inside pytest)."""
    try:
        signal.signal(signal.SIGTERM, lambda *_: shutdown.set())
        signal.signal(signal.SIGINT, lambda *_: shutdown.set())
        signal.signal(signal.SIGUSR1, lambda *_: reload_event.set())
    except ValueError:
        log.warning("signal handlers not installed (not main thread)")


def _write_pidfile() -> None:
    pid_dir = Path("/run/smart-gate")
    try:
        pid_dir.mkdir(parents=True, exist_ok=True)
        (pid_dir / "pid").write_text(str(os.getpid()))
    except PermissionError:
        log.warning("cannot write pidfile (likely running outside systemd)")


def _consume_bus(bus: queue.Queue, db: Database, matcher: Matcher,
                 uart: UartClient, trig_queue: queue.Queue, cfg, shutdown,
                 reload_event: threading.Event,
                 *, auto_enroll_state: AutoEnrollPairState | None = None,
                 gate_tracker: GateTracker | None = None,
                 esp_log_bus: EspLogBus | None = None,
                 esp_log_writer: EspLogWriter | None = None,
                 peripherals: PeripheralTracker | None = None) -> None:
    # Per-channel cooldowns live in the detector now (face_cooldown /
    # qr_cooldown). last_grant is retained as an opaque handle for the
    # checkin signature — _handle_checkin no longer reads it.
    last_grant: dict[int, float] = {}
    while not shutdown.is_set():
        if reload_event.is_set():
            reload_event.clear()
            matcher.reload(db)
            log.info("matcher reloaded")
        try:
            evt = bus.get(timeout=0.5)
        except queue.Empty:
            continue
        try:
            if isinstance(evt, CheckInEvent):
                _handle_checkin(evt, db, matcher, uart, trig_queue, cfg,
                                last_grant, reload_event, esp_log_bus,
                                gate_tracker=gate_tracker)
            elif isinstance(evt, AuthEvent):
                # Manual_open / manual_close only — bypasses 1-of-3 routing.
                _handle_manual_event(evt, db, uart, trig_queue, esp_log_bus)
            elif isinstance(evt, EspEvent):
                _handle_esp_event(evt, db, matcher, bus, trig_queue,
                                  uart, cfg, last_grant, reload_event,
                                  auto_enroll_state=auto_enroll_state,
                                  gate_tracker=gate_tracker,
                                  esp_log_bus=esp_log_bus,
                                  esp_log_writer=esp_log_writer,
                                  peripherals=peripherals)
        except Exception:
            # An unhandled exception in a handler (DB write failure, schema
            # drift, etc.) used to kill this thread silently — daemon stayed
            # "running" but processed no events. Log it, emit a synthetic
            # audit so the operator sees it on the dashboard, back off, and
            # keep going.
            log.exception("bus consumer iter failed; continuing")
            try:
                _audit(esp_log_bus, "error", "internal",
                       "bus consumer exception — see app.log")
            except Exception:
                pass
            time.sleep(0.5)


def _audit(esp_log_bus, lvl: str, tag: str, msg: str,
           direction: str = "—") -> None:
    """Publish a synthetic log line to the live audit stream.
    `direction` is "→" for Pi→ESP, "←" for ESP→Pi, "—" for internal."""
    if esp_log_bus is None:
        return
    esp_log_bus.publish({
        "ts": time.strftime("%Y-%m-%d %H:%M:%S"),
        "lvl": lvl, "tag": tag, "msg": msg, "direction": direction,
        "synthetic": True,
    })


def _handle_checkin(evt: CheckInEvent, db, matcher, uart, trig_queue, cfg,
                    last_grant, reload_event, esp_log_bus=None,
                    gate_tracker: GateTracker | None = None):
    """1-of-3 channel router. Each method writes exactly one event row.

    - face / qr → Pi sends cmd:open to ESP (ESP doesn't know about these).
    - rfid     → ESP already opened the gate via its NVS allowlist shortcut.
                 Pi only mirrors the event row; sending cmd:open again would
                 race with the ESP's in-flight ack and double-log.

    Per-channel cooldowns live upstream (detector's `face_cooldown` /
    `qr_cooldown`; ESP allowlist for RFID). `last_grant` is unused here
    today — kept in the signature for future cross-channel throttling.
    """
    del last_grant  # explicitly unused — see docstring
    name = matcher.user_name(evt.user_id)
    if name is None or name == f"id={evt.user_id}":
        # Matcher returns "id=<n>" when the user_id isn't in its name map.
        # That happens for unknown users — refuse to write an event row.
        _audit(esp_log_bus, "warn", evt.method,
               f"unknown user_id={evt.user_id}")
        return

    # Attribute the latest open to a name for the dashboard widget. Must
    # happen before any potential exception path below so the field reflects
    # the user even if downstream DB / UART work raises.
    if gate_tracker is not None:
        gate_tracker.set_last_user(name)

    # Channel-specific detail field for the event row.
    if evt.face_distance is not None:
        detail = f"distance={evt.face_distance:.3f}"
    elif evt.raw_uid is not None:
        detail = f"uid={evt.raw_uid}"
    elif evt.qr_token is not None:
        detail = f"token={evt.qr_token}"
    else:
        detail = None

    # Wrap the event-row insert + last_seen update in one transaction so
    # both writes share a single fsync instead of two (NORMAL sync still
    # flushes WAL on each COMMIT).
    with db.transaction():
        ev_id = db.insert_event(evt.method, evt.user_id, True, detail=detail)
        db.touch_last_seen(evt.user_id)

    # RFID already opened the gate on the ESP side — don't duplicate.
    if evt.method != "rfid":
        _audit(esp_log_bus, "info", "cmd",
               f"open user={name} reason={evt.method}", direction="→")
        try:
            ack = uart.send_cmd("open", {"user": name, "reason": evt.method},
                                timeout=2.0)
            _audit(esp_log_bus, "info", "ack",
                   f"open OK ({ack})" if ack else "open ack",
                   direction="←")
        except (LinkDown, LinkTimeout) as e:
            log.warning("uart open failed: %s", e)
            _audit(esp_log_bus, "err", "cmd",
                   f"open FAILED: {e} — peripheral unreachable",
                   direction="←")
    else:
        _audit(esp_log_bus, "info", "rfid",
               f"granted user={name} (ESP already opened)", direction="←")

    try:
        trig_queue.put_nowait(RecordingTrigger(ev_id, evt.ts_mono))
    except queue.Full:
        log.warning("trigger_queue full, dropping clip for event %d", ev_id)


def _trigger_auto_enroll(enroll: EnrollCandidate, db, matcher,
                         reload_event, esp_log_bus=None) -> None:
    """RFID-paired auto-enroll: insert a new face_encoding row for the
    grant user and signal the matcher to reload."""
    user_name = matcher.user_name(enroll.grant_user_id)
    if user_name is None or user_name == f"id={enroll.grant_user_id}":
        return
    # sample_idx = current count so each insert gets a unique index.
    n_samples = db.connect().execute(
        "SELECT COUNT(*) FROM face_encodings WHERE user_id=?",
        (enroll.grant_user_id,),
    ).fetchone()[0]
    db.insert_face_encoding(enroll.grant_user_id,
                            enroll.embedding.astype("float32").tobytes(),
                            n_samples)
    log.info("auto-enrolled face under user_id=%d via rfid (now %d samples)",
             enroll.grant_user_id, n_samples + 1)
    _audit(esp_log_bus, "info", "enroll",
           f"auto-bind face → {user_name} via rfid (sample {n_samples + 1})",
           direction="—")
    if reload_event is not None:
        reload_event.set()


def _handle_manual_event(evt: AuthEvent, db, uart, trig_queue, esp_log_bus=None):
    """Manual_open / manual_close from web button — bypasses 2FA."""
    if evt.method not in ("manual_open", "manual_close"):
        return  # ignore legacy face/qr events that shouldn't be emitted now
    verb = "open" if evt.method == "manual_open" else "close"
    payload = {"user": "admin", "reason": "manual"} if verb == "open" else None
    _audit(esp_log_bus, "info", "cmd",
           f"{verb} (manual from web)", direction="→")
    try:
        ack = uart.send_cmd(verb, payload, timeout=2.0)
        _audit(esp_log_bus, "info", "ack",
               f"{verb} OK ({ack})" if ack else f"{verb} ack",
               direction="←")
    except (LinkDown, LinkTimeout) as e:
        log.warning("uart %s failed: %s", verb, e)
        _audit(esp_log_bus, "err", "cmd",
               f"{verb} FAILED: {e} — peripheral unreachable",
               direction="←")
    db.insert_event(evt.method, None, True)
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

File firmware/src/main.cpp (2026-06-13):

#include <Arduino.h>
#include <esp_task_wdt.h>
#include <esp_system.h>
#include <esp_heap_caps.h>
#include <ArduinoJson.h>
#include "freertos/FreeRTOS.h"
#include "freertos/queue.h"
#include "freertos/timers.h"

#include "../include/config.h"
#include "../include/events.h"
#include "../include/version.h"
#include "../include/log.h"

#include "uart_link.h"
#include "rfid.h"
#include "sensor.h"
#include "gate_fsm.h"
#include "servo_drv.h"
#include "lcd_drv.h"
#include "buzzer_drv.h"
#include "allowlist.h"

// === Global queues + timers (extern'd in module headers) ===
QueueHandle_t g_event_q    = nullptr;
QueueHandle_t g_outbound_q = nullptr;
TimerHandle_t g_open_reached_timer    = nullptr;
TimerHandle_t g_passage_timeout_timer = nullptr;
TimerHandle_t g_warn_giveup_timer     = nullptr;
TimerHandle_t g_close_reached_timer   = nullptr;
TimerHandle_t g_heartbeat_timer       = nullptr;
TimerHandle_t g_lcd_restore_timer     = nullptr;
TimerHandle_t g_lcd_icon_timer        = nullptr;
TimerHandle_t g_obstacle_warn_timer   = nullptr;
TimerHandle_t g_servo_stall_timer     = nullptr;
TimerHandle_t g_recovery_timer        = nullptr;

// Captured once at boot before gate_fsm_init() so it can decide whether to enter
// the brown-out recovery path (Tasks 3.9 + 3.10). Pointer to a static string in
// reset_reason_string()'s switch — safe to share across translation units.
const char* g_reset_reason_str = "unknown";

static void cb_lcd_restore(TimerHandle_t) {
  event_t e{}; e.kind = EV_T_LCD_RESTORE;
  xQueueSend(g_event_q, &e, 0);   // best-effort; drop on full queue
}

static void cb_lcd_icon(TimerHandle_t) {
  event_t e{}; e.kind = EV_T_LCD_ICON_TICK;
  xQueueSend(g_event_q, &e, 0);
}

static void cb_obstacle_warn(TimerHandle_t) {
  event_t e{}; e.kind = EV_T_OBSTACLE_WARN_FIRED;
  xQueueSend(g_event_q, &e, 0);
}

static void cb_servo_stall(TimerHandle_t) {
  event_t e{}; e.kind = EV_T_SERVO_STALL;
  xQueueSend(g_event_q, &e, 0);
}

static void cb_recovery(TimerHandle_t) {
  event_t e{}; e.kind = EV_T_RECOVERY_FALLBACK;
  xQueueSend(g_event_q, &e, 0);
}

static const char* reset_reason_string() {
  switch (esp_reset_reason()) {
    case ESP_RST_POWERON:  return "power_on";
    case ESP_RST_SW:       return "sw_reset";
    case ESP_RST_PANIC:    return "panic";
    case ESP_RST_INT_WDT:  return "watchdog";
    case ESP_RST_TASK_WDT: return "watchdog";
    case ESP_RST_WDT:      return "watchdog";
    case ESP_RST_BROWNOUT: return "brownout";
    default:               return "other";
  }
}

static void emit_boot_event() {
  JsonDocument doc;
  doc["type"] = "evt";
  doc["v"]    = "boot";
  doc["data"]["fw"]            = FW_VERSION;
  doc["data"]["free_heap"]     = (uint32_t)esp_get_free_heap_size();
  doc["data"]["reset_reason"]  = reset_reason_string();
  outbound_msg_t out;
  size_t w = serializeJson(doc, out.json, sizeof out.json);
  if (w > 0 && w < sizeof out.json) outbound_send(out);
}

void setup() {
  // 1. Status LED
  pinMode(PIN_LED_STATUS, OUTPUT);
  digitalWrite(PIN_LED_STATUS, LOW);

  // 2. UARTs up early (so logs work).
  //    Serial  (UART0, GPIO 1/3, USB-CDC) → `pio device monitor` debug + ESP_LOG sink.
  //    Serial1 (UART1, GPIO 32/25)        → Pi app comm; configured inside uart_link_init().
  Serial.begin(UART_BAUD);
  uart_link_init();

  // 3. NVS / allowlist
  allowlist_init();

  // 4. Peripheral init
  servo_init();
  lcd_init();
  buzzer_init();
  rfid_init();
  sensor_init();

  // 5. Queues
  g_event_q    = xQueueCreate(EVENT_QUEUE_LEN,    sizeof(event_t));
  g_outbound_q = xQueueCreate(OUTBOUND_QUEUE_LEN, sizeof(outbound_msg_t));
  if (!g_event_q || !g_outbound_q) {
    ESP_LOGE("main", "queue alloc failed");
    while (1) vTaskDelay(pdMS_TO_TICKS(1000));
  }

  // 6. Timers
  g_open_reached_timer    = xTimerCreate("openR", pdMS_TO_TICKS(DEFAULT_OPEN_REACHED_MS),   pdFALSE, nullptr, cb_open_reached);
  g_passage_timeout_timer = xTimerCreate("passT", pdMS_TO_TICKS(DEFAULT_PASSAGE_TIMEOUT_MS),pdFALSE, nullptr, cb_passage_timeout);
  g_warn_giveup_timer     = xTimerCreate("warnG", pdMS_TO_TICKS(DEFAULT_WARN_GIVEUP_MS),    pdFALSE, nullptr, cb_warn_giveup);
  g_close_reached_timer   = xTimerCreate("closeR",pdMS_TO_TICKS(DEFAULT_CLOSE_REACHED_MS),  pdFALSE, nullptr, cb_close_reached);
  g_heartbeat_timer       = xTimerCreate("hb",    pdMS_TO_TICKS(HEARTBEAT_INTERVAL_MS),     pdTRUE,  nullptr, cb_heartbeat);
  g_lcd_restore_timer     = xTimerCreate("lcdRst",pdMS_TO_TICKS(2500),                      pdFALSE, nullptr, cb_lcd_restore);
  g_lcd_icon_timer        = xTimerCreate("lcdIcon",pdMS_TO_TICKS(200),                      pdTRUE,  nullptr, cb_lcd_icon);  // pdTRUE = periodic
  g_obstacle_warn_timer   = xTimerCreate("obsWarn",pdMS_TO_TICKS(5000),                     pdFALSE, nullptr, cb_obstacle_warn);
  // Stall watchdog period is rewritten on each arm (2× expected travel); the
  // 2000 ms here is a safe placeholder for the create-time period.
  g_servo_stall_timer     = xTimerCreate("svStl", pdMS_TO_TICKS(2000),                      pdFALSE, nullptr, cb_servo_stall);
  g_recovery_timer        = xTimerCreate("recov", pdMS_TO_TICKS(RECOVERY_HOLD_MS),           pdFALSE, nullptr, cb_recovery);

  // 7. FSM init (loads NVS config, applies servo angles).
  //    Capture reset_reason FIRST so gate_fsm_init() can branch into the
  //    brown-out recovery path (Tasks 3.9 + 3.10) when the last persisted
  //    FSM state was mid-motion (OPENING/OPEN_WAIT/TIMEOUT_WARN/CLOSING).
  g_reset_reason_str = reset_reason_string();
  gate_fsm_init();

  // 8. Task watchdog: 8s timeout, panic on expiry
  // Using 2-arg form: IDF bundled with arduino-esp32 3.x / platform=espressif32@^6 uses
  // esp_task_wdt_init(uint32_t timeout_seconds, bool panic) — not the IDF 5.x struct form.
  esp_task_wdt_init(8, true);

  // 9. Spawn tasks
  xTaskCreatePinnedToCore(uart_link_task,  "uart_link",  4096, nullptr, 3, nullptr, 0);
  xTaskCreatePinnedToCore(rfid_task,       "rfid",       3072, nullptr, 2, nullptr, 1);
  xTaskCreatePinnedToCore(sensor_task,     "sensor",     2048, nullptr, 2, nullptr, 1);
  xTaskCreatePinnedToCore(gate_fsm_task,   "gate_fsm",   4096, nullptr, 4, nullptr, 1);

  // 10. Start heartbeat
  xTimerStart(g_heartbeat_timer, 0);
  xTimerStart(g_lcd_icon_timer, 0);

  // 11. Boot event
  emit_boot_event();
  digitalWrite(PIN_LED_STATUS, HIGH);
}

void loop() {
  // All work is in FreeRTOS tasks.
  vTaskDelay(pdMS_TO_TICKS(1000));
}

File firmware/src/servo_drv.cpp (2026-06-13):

#include "servo_drv.h"
#include "../include/config.h"
#include <Arduino.h>
#include <ESP32Servo.h>
#include "freertos/FreeRTOS.h"
#include "freertos/timers.h"

static Servo s_servo;
static int s_open_deg  = DEFAULT_SERVO_OPEN_DEG;
static int s_close_deg = DEFAULT_SERVO_CLOSE_DEG;
static TimerHandle_t s_detach_timer = nullptr;

static void cb_detach(TimerHandle_t) {
  // Release PWM and drive the line LOW so the SG90 coil stops drawing idle
  // current (~6 mA hum + heat). Next servo_command_async() re-attaches.
  if (s_servo.attached()) s_servo.detach();
  digitalWrite(PIN_SERVO, LOW);
}

void servo_init() {
  pinMode(PIN_SERVO, OUTPUT);
  digitalWrite(PIN_SERVO, LOW);
  s_servo.setPeriodHertz(50);
  s_servo.attach(PIN_SERVO, 500, 2400);  // typical SG90 pulse range µs
  s_servo.write(s_close_deg);
  // Detach timer is one-shot; period is rewritten on each command via
  // xTimerChangePeriod() so the 1000 ms placeholder here is irrelevant.
  s_detach_timer = xTimerCreate("svDet", pdMS_TO_TICKS(1000),
                                pdFALSE, nullptr, cb_detach);
}

void servo_set_angles(int open_deg, int close_deg) {
  // Clamp to physical safe range — protects against a bad cmd:config (e.g.
  // servo_open_deg=180) driving the horn into the enclosure wall and
  // stalling SG90 at ~700 mA until brown-out.
  s_open_deg  = constrain(open_deg,  SERVO_MIN_PHYS_DEG, SERVO_MAX_PHYS_DEG);
  s_close_deg = constrain(close_deg, SERVO_MIN_PHYS_DEG, SERVO_MAX_PHYS_DEG);
}

void servo_open()  { s_servo.write(s_open_deg); }
void servo_close() { s_servo.write(s_close_deg); }
int  servo_open_deg()  { return s_open_deg; }
int  servo_close_deg() { return s_close_deg; }

void servo_command_async(int target_deg, int expected_travel_ms) {
  target_deg = constrain(target_deg, SERVO_MIN_PHYS_DEG, SERVO_MAX_PHYS_DEG);
  if (!s_servo.attached()) {
    s_servo.attach(PIN_SERVO, 500, 2400);
  }
  s_servo.write(target_deg);
  if (s_detach_timer) {
    xTimerChangePeriod(s_detach_timer,
                       pdMS_TO_TICKS(expected_travel_ms + 200), 0);
    xTimerStart(s_detach_timer, 0);
  }
}

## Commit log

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2026-05-22 fix(firmware): null-guard outbound_q in uart_link TX drain
    Same defensive pattern as outbound_post/outbound_send. Prevents a crash if
    task creation order in Task 9 ever changes such that uart_link_task starts
    before g_outbound_q is initialized.
    [uart_link.cpp]
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2026-05-22 fix(kicad): use library mounting hole footprint to survive save/load
    Previously add_outline_and_mounts.py built mount holes from a bare
    pcbnew.FOOTPRINT(board) call without setting a library reference. KiCad 6
    silently discarded them on save (no valid footprint identifier). Switched to
    pcbnew.FootprintLoad(MountingHole, MountingHole_3.2mm_M3) which yields proper
    library-backed footprints that persist through Save()/Load() cycles.
    [smart_gate_carrier.kicad_pcb]
2026-05-22 pivot(kicad): combined motherboard (Pi5 + ESP32 on one PCB)
    Architecture pivot per spec rev 2026-05-22 §2/§5/§6:
    - Single 250x150mm motherboard hosts both Pi 5 (2x20 GPIO socket) and
    ESP32 DevKit (30-pin socket).
    - Single 12V input -> on-board buck 5V/5A feeds both subsystems.
    - Pi powered via GPIO pin 2/4; runtime UART app comm via Pi GPIO 14/15
    to ESP32 GPIO 5/17 (UART1 remapped via matrix).
    - USB cable retained only for ESP32 firmware flashing.
    Old ESP32-only design archived under kicad/archive/ for reference.
    Build pipeline (same flow, new content):
    1. build_combined.py -> SKiDL netlist (31 components, 0 ERC errors)
    2. add_outline_and_mounts.py -> 250x150 Edge.Cuts + 4 M3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
    [smart_gate_carrier.kicad_pcb, smart_gate_carrier.kicad_sch, smart_gate_combined.kicad_pcb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]
2026-05-22 fix(kicad): Pi 4 target + all-THT footprints
    Two clarifications from user 2026-05-22:
    1. Hardware is Raspberry Pi 4 (not Pi 5 as previously assumed). GPIO layout
    identical, but power budget relaxed (1.5A peak vs 5A) and Pi 4 has no
    strict PMIC so GPIO-fed 5V is safer.
    2. All discrete components must be through-hole (THT), not SMD — user does
    not have reflow/hot-air, prefers hand-soldering.
    Changes:
    - Spec §1, §2, decision log: Pi 5 -> Pi 4, buck 5A -> 3A, peak 3.6A -> 2.1A
    - Spec §2: AMS1117 SOT-223 -> LM1117-3.3 TO-220
    - Spec risks 6: Pi 4 tolerance noted (more forgiving than Pi 5)
    - Spec decisions 23-24: THT preference + Pi 4 target documented
    - SKiDL build_combined.py: all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
    [smart_gate_combined.kicad_pcb]
2026-05-22 fix(kicad): single 2x15 ESP32 DevKit footprint, custom 25.4mm rail spacing
    Replaced 2x Conn_01x15 sockets (J_ESP_L + J_ESP_R) with single
    Conn_02x15_Odd_Even using a project-local custom footprint
    ESP32_DevKit_V1_30pin (kicad/smart_gate_combined/footprints.pretty/).
    Benefit: rail-to-rail spacing of 25.4mm guaranteed by the footprint itself,
    not by separate footprint placements that could drift. DevKit will fit
    exactly when soldered.
    Pin numbering uses standard Conn_02x15_Odd_Even convention (odd = left
    rail top-to-bottom, even = right rail top-to-bottom).
    Also patched import_netlist.py to try the project-local footprints.pretty
    directory before falling back to the system KiCad footprint l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
    [smart_gate_combined.kicad_pcb, smart_gate_combined.kicad_sch]
2026-05-22 feat(kicad): LM2596 mini module custom footprint
    Replaced generic 4-pin header for buck connection with custom footprint
    LM2596_Mini_Buck matching the physical layout of the common ~43x21mm
    LM2596 module sold in Vietnam:
    - 4 corner pads (not in-line)
    - IN pair on left, OUT pair on right (35mm apart)
    - V+ on top, GND on bottom (14mm apart)
    - 1.0mm drill, 2.0mm pad for wire-thick pins
    User can solder the module directly onto the motherboard via the 4 corner
    pads. If physical module dimensions differ, edit footprint pad coords.
    [smart_gate_combined.kicad_pcb]
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2026-05-22 fix(kicad): LM2596S adjustable buck — corrected pad spacing 37x13mm
    LM2596S adjustable mini buck module standard dimensions:
    - PCB body: 43 x 21 mm (unchanged in silkscreen outline)
    - Pad spacing horizontal IN-to-OUT: 37 mm (was 35mm, off by 2mm)
    - Pad spacing vertical V+ to GND: 13 mm (was 14mm, off by 1mm)
    - Drill: 1.2mm (was 1.0mm), pad: 2.2mm (was 2.0mm) for ~0.1mm headroom
    User does not have caliper to verify exact module dimensions — these are
    the most-cited values from cheap Chinese LM2596S modules common in Vietnam.
    If actual module's pads don't align, edit (at X Y) in the 4 pad lines of
    footprints.pretty/LM2596_Mini_Buck.kicad_mod and re-run pipeline.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
    [smart_gate_combined.dsn, smart_gate_combined.kicad_pcb, smart_gate_combined.kicad_sch]
2026-05-22 fixes+spec: USB-CDC pinned (pyserial no auto-reset + spec §4.1 rollback)
    #2 Pi-app: _open_serial now passes dsrdtr=False,rtscts=False and forces
    ser.dtr=False, ser.rts=False after open so CP2102/CH340 DTR-to-EN wiring
    does not auto-reset the ESP32 every daemon reconnect.
    #4 Spec §4.1 + §1 overview + decision log: roll back the 2026-05-22 GPIO
    UART pivot (decisions #21, #22). Runtime + esptool flash share one USB
    cable from Pi USB-A to DevKit USB-C/micro-USB, exposed on Pi as
    /dev/ttyUSB0 — matches existing firmware pin map (GPIO 5/17 = RC522
    CS/RST per firmware/include/config.h) and existing Pi-app code. Adds
    decision #25 documenting the rollback rationale and the residual
    follow-up: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
    [uart_client.py]
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2026-05-22 feat(kicad): force B.Cu signal routing + flip GND pour to F.Cu
    User wants components on opposite side from wires. For THT prototype:
    - Components remain on F.Cu (top, body + silkscreen)
    - Wires route on B.Cu (bottom) only — clean separation
    - GND copper pour moves to F.Cu (fills around components on top)
    Implementation:
    - autoroute.py post-processes DSN to set F.Cu type=power (not signal)
    -> FreeRouting routes only on B.Cu
    - add_gnd_pour.py now creates zone on F.Cu (was B.Cu)
    - Removed FB_PI ferrite bead — Pi GPIO 5V now ties directly to +5V net
    Result: 282 B.Cu tracks (88%%) vs 37 F.Cu tracks (12%% are unavoidable
    pad escape stubs). 7 vias for B->F transitions.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
    [smart_gate_combined.dsn, smart_gate_combined.kicad_pcb]
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2026-05-22 fix(kicad): remove pcbnew.ImportSpecctraSES — shifted everything via aux origin
    KiCad 6's ImportSpecctraSES applies an internal aux-origin offset when
    re-importing the SES that ExportSpecctraDSN added during export. Effect:
    footprints + edge cuts ended up shifted ~28-83 mm in X/Y after a roundtrip,
    making the GND pour (placed at script coordinates) appear misaligned vs
    the board outline (which had drifted).
    Fix: autoroute.py no longer calls ImportSpecctraSES. Custom import_ses.py
    parses the SES coordinates directly and adds tracks without touching
    footprint positions.
    After full pipeline re-run:
    Edge.Cuts: X [100, 350], Y [100, 250] (correct, 250x150mm)
    H1: (105, 105)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
    [smart_gate_combined.dsn, smart_gate_combined.kicad_pcb]
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2026-05-22 feat(firmware): switch Pi link from USB-CDC to GPIO UART1 (decision #26)
    Runtime Pi↔ESP32 app comm now uses ESP32 UART1 on GPIO 32 (RX) / GPIO 25
    (TX), routed through the Pi GPIO header pins 8/10 (BCM14/15). UART0
    (GPIO 1/3, USB-CDC) stays exclusively for `pio device monitor` debug and
    `esptool.py` flashing.
    Architecture spec was updated 2026-05-23 on main (commits 14bf951 +
    de14c5e) but the firmware code was tagged "NOT YET APPLIED" — this
    commit closes that gap.
    - config.h: add PIN_PI_UART_RX=32, PIN_PI_UART_TX=25
    - uart_link.cpp: replace Serial.* with Serial1.* and use the pin-aware
    begin overload Serial1.begin(UART_BAUD, SERIAL_8N1, RX, TX)
    - main.cpp: add explicit Seria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
    [config.h, main.cpp, uart_link.cpp]
2026-05-22 fix(kicad): auto-fit GND pour to actual Edge.Cuts + 0.7mm track width
    User reported pour misaligned after restoring backup PCB whose outline
    sits at (72.3,17.5)->(274.0,137.1) due to the earlier ImportSpecctraSES
    roundtrip-shift. The pour was hardcoded to pcb_common.BOARD_ORIGIN_X/Y
    constants (100/100) which no longer match the board.
    Fixes:
    - add_gnd_pour.py reads Edge.Cuts geometry from the loaded board to
    derive the zone outline at runtime — always fits whatever rectangle
    KiCad has on Edge.Cuts.
    - import_ses.py overrides SES-encoded 0.25mm track width to 0.7mm
    uniformly via FORCE_TRACK_WIDTH_NM constant.
    After re-route:
    Board outline: (72.3,17.5)->(274.0,137.1)
    Zone outline: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
    [smart_gate_combined.dsn, smart_gate_combined.kicad_pcb]
2026-05-22 tune(kicad): track width 1.0mm — prevents routing between component pins
    User asked to enlarge tracks to 1mm AND ensure tracks do not weave
    between adjacent component pins (e.g., between pin 5 and 6 of a 1x15
    header at 2.54mm pitch).
    At 2.54mm pitch with 1.8mm pads, the gap between adjacent pad edges is
    ~0.74mm — a 1.0mm track + 0.2mm clearance needs 1.4mm minimum width to
    fit. Physically impossible, so FreeRouting now routes AROUND component
    pin clusters.
    - import_ses.py: FORCE_TRACK_WIDTH_NM = 1_000_000 (was 700_000)
    - autoroute.py: DSN width override 250um -> 1000um before FreeRouting runs
    (so FreeRouting plans routes that actually fit at the new width)
    Result: 286 track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
    [smart_gate_combined.dsn, smart_gate_combined.kicad_pcb]
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2026-05-23 log-throttle missing-peripheral warnings; suppress cv2 native stderr
    Daemon stays running (it already retried indefinitely) but the journal
    was spammed every 5s with "camera not available" and every reconnect
    backoff cycle with "link open failed". On a unit with the camera or
    ESP32 unplugged this filled /var/log/smart-gate/app.log with hundreds of
    MB per hour.
    smart_gate/video/capture.py:
    - _open_camera now tracks fail_count and last_log_mono. Logs WARNING on
    the first failure (with hint that messages will be throttled), then at
    most once per 60s thereafter. Logs INFO on recovery noting the retry
    count.
    - Top of module sets OPENCV_LOG_LEVEL=ERROR via os.environ.setdefault so
    cv2's n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
    [uart_client.py]
2026-05-23 route(kicad): full re-route with both layers, 50 passes, clearance 0.2mm
    Best result after multiple iterations:
    - Both F.Cu + B.Cu signal routing (was B.Cu-only — too tight at 1mm width)
    - 50 max passes (was 20)
    - Clearance 0.2mm in Default net class (was 0.4mm — overly strict)
    - Dedupe duplicate same-net vias post-import
    Result:
    - 546 tracks (F.Cu 26%, B.Cu 74%) + 66 vias
    - 44 DRC violations: 2 errors (unconnected BUZ_COLLECTOR), 42 warnings
    - 38 via_dangling warnings (Local override severity)
    - 2 unconnected_items in buzzer area — user to route manually
    - 4 PCB_DIM_ALIGNED dimension annotations (caused edge_clearance error)
    - 58 duplicate vias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
    [smart_gate_combined.dsn, smart_gate_combined.kicad_pcb]
2026-05-23 fix(kicad): clear_tracks now removes vias properly (was checking 'VIA' not 'PCB_VIA')
    Root cause of accumulating duplicate vias on every re-route: clear_tracks.py
    checked GetClass() == 'VIA' but KiCad 6 returns 'PCB_VIA'. So vias were never
    deleted, just accumulated across pipeline runs.
    Pipeline now produces CLEAN routing:
    238 tracks + 4 vias (was 332-738 tracks + 33-75 vias)
    DRC: 6 warnings (cosmetic silk only), 0 errors, 0 unconnected pads
    Also changes:
    - Track width 1.0mm -> 0.5mm (FreeRouting can fit tracks between pins now)
    - Both F.Cu + B.Cu signal routing (allowed both layers)
    - Skip dedup vias (no longer needed after clear_tracks fix)
    - Remove dimension annotations on PCB load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
    [smart_gate_combined.dsn, smart_gate_combined.kicad_pcb]
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2026-05-23 link: defensive try/except wrappers in rx/tx loops; catch all encoding errors
    Root cause: when ESP32 has not been flashed with the GPIO-UART firmware,
    GP25 (TX from ESP32's side) floats and Pi /dev/serial0 RX picks up random
    bytes. pyserial.readline() returns these as a bytes object. json.loads()
    on bytes auto-detects encoding via the first 4 bytes' BOM/pattern and,
    for some noise patterns, dispatches to utf-32-be — which then raises
    UnicodeDecodeError, NOT JSONDecodeError. protocol.decode only caught
    JSONDecodeError so the UnicodeDecodeError propagated up through
    _rx_loop's narrow except (only SerialException + ProtocolError) and out
    of the thread, permanently killing uart-rx.
    Observed i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
    [uart_client.py]
2026-05-23 protocol: catch UnicodeError siblings in decode()
    Companion fix to 9f14b4f. The previous commit's protocol.py edit didn't
    make it into the commit (likely cross-session race). Re-apply: decode()
    now catches (JSONDecodeError, UnicodeDecodeError, UnicodeError) — the
    trio json.loads can raise on bytes input with auto-detected encoding.
    Without this, floating UART RX bytes still kill uart-rx the moment they
    trip utf-32-be detection. With both this and 9f14b4f's outer try/except
    the thread is double-defended.
    [protocol.py]
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2026-05-23 web: live bbox overlay on MJPEG + runtime enroll endpoint
    New OverlayState (recognition/overlay.py) shares the latest face
    bounding box + match label between the detector thread and the Flask
    MJPEG generator. State expires after stale_after_s seconds so a stale
    bbox doesn't persist after the face leaves the frame.
    Detector now reports per-frame to OverlayState:
    - Green bbox + "<name> (<distance>)" on match
    - Red bbox + "stranger (<distance>)" on stranger
    - Yellow bbox + "? (<distance>)" in uncertain band
    - Cleared when no face detected
    Flask MJPEG generator (/stream.mjpeg) switched from pre-encoded JPEG
    (cap thread) to BGR + re-encode with bbox drawn. cv2 rectangle + label
    on each frame. C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
    [main.py]
2026-05-23 auto-enroll: bind unknown face to QR/RFID user on first grant
    Workflow change per user request:
    - Green bbox = face already in DB (matched)
    - Red bbox = face NOT in DB (anything else, no more yellow)
    - When a granted QR scan or RFID swipe arrives AND the most recent face
    in frame was red, the daemon auto-binds that face's embedding under
    the credential's user_id. Next frame the face is green with the ID.
    - Dashboard "Tạo user mới" button creates an empty user + QR PNG (no
    face capture). Operator prints the QR; user holds QR up to webcam to
    bind their face the first time. face_capture=true is still supported
    in the API body for the old behaviour.
    New module recognition/pending_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
    [main.py]
2026-05-23 feat(kicad): GND copper pour on both F.Cu and B.Cu layers
    add_gnd_pour.py now adds two GND zones (one per copper layer), both
    fitting the Edge.Cuts geometry with 0.5mm margin. Removed leftover
    single-zone code from earlier single-layer version.
    Final PCB state:
    - 238 signal tracks @ 0.5mm (F.Cu 112 + B.Cu 126)
    - 4 vias
    - 2 GND copper pour zones (F.Cu + B.Cu)
    - 31 footprints
    - DRC: 0 errors, 0 unconnected pads, 6 cosmetic silk warnings
    Ready for gerber export and fab.
    [smart_gate_combined.kicad_pcb]
2026-05-23 feat(kicad): export 3D STEP via kicad2step for FreeCAD enclosure design
    Generated kicad/smart_gate_combined/3d/smart_gate_combined.step (767KB)
    using KiCad 6's kicad2step CLI tool. STEP includes board outline + 3D
    models for all components that have associated .step models in the
    KiCad library.
    Use case: import into FreeCAD when designing the enclosure to ensure
    mechanical clearances around connectors, headers, and the Pi/DevKit
    sockets.
    [smart_gate_combined.step]
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2026-05-23 gate state tracking + timeout alert badge on dashboard
    ESP32 already owns the gate FSM (architecture spec §4.5: idle → opening
    → open → timeout_warn → closing → closed) with a buzzer pattern during
    timeout_warn. Pi was discarding evt:gate messages; this commit makes Pi
    mirror the state and surface it.
    New module link/gate_state.py:
    - GateTracker — thread-safe state holder with update() returning the
    previous state on transitions, and snapshot() for HTTP exposure.
    main.py:
    - Instantiate GateTracker, pass to bus consumer + flask thread.
    - _handle_esp_event on evt:gate updates the tracker. When state
    transitions INTO timeout_warn, insert an event row
    (method='timeout', gran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
    [gate_state.py, main.py]
2026-05-23 feat(link): EspLogBus pub/sub for live log streaming
    In-memory pub/sub with bounded per-subscriber deques (default cap 200).
    Single publisher (main._handle_esp_event for evt:log) and N subscribers
    (one per open SSE connection). Slow consumers see oldest items dropped
    silently; the producer never blocks.
    Fix: use list (not set) for _subscribers — collections.deque is not
    hashable, so set.add() raises TypeError on Python 3.10.
    [esp_log_bus.py]
2026-05-23 fix(link): EspLogBus.unsubscribe must use object identity
    list.remove(q) used value equality; two empty deques compare equal so
    bus.unsubscribe(q1) could silently remove q2 if both were empty.
    Replace with an identity-based scan. Regression test added.
    [esp_log_bus.py]
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2026-05-23 feat(main): publish ESP32 log events to EspLogBus
    bus-consumer now forwards every evt:log to an EspLogBus alongside the
    DB INSERT (using the returned row id). The bus is constructed in main()
    and passed both to the consumer and to the Flask app for the upcoming
    SSE endpoint. create_app accepts esp_log_bus but doesn't use it yet.
    [main.py]
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2026-05-23 dashboard: live log panel with cmd/ack/warn audit stream
    User asked for right-side notification log showing commands sent to
    ESP32 and responses, including peripheral errors and warnings.
    - New _audit(esp_log_bus, lvl, tag, msg, direction) helper publishes
    synthetic log entries (no DB row) onto the existing esp_log_bus
    pub/sub. Direction is '→' (Pi→ESP), '←' (ESP→Pi), or '—' (internal).
    - _handle_checkin emits:
    → cmd: open user=X reason=qr (distance=0.42)
    ← ack: open OK ({'ok': true}) on success
    ← cmd: open FAILED: <reason> on LinkDown/LinkTimeout
    — enroll: auto-bind face → user_X via qr (sample N) when auto-enroll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
    [main.py]
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2026-05-23 web: /peripherals tab + PeripheralTracker
    User reported that disconnected peripherals (servo, RC522, LCD, HC-SR04,
    buzzer) produced no visible warning. The daemon already received some
    hints (e.g. evt:log warn sensor "no echo for 30s") but they were buried
    in /system live log. New /peripherals page surfaces per-device health
    with auto-refresh cards.
    New module link/peripheral_status.py:
    - PeripheralTracker tracks 6 logical peripherals: rfid, lcd, sensor,
    servo, buzzer, link.
    - update_from_log(lvl, tag, msg, ts): classifies based on lvl + text
    patterns ("no echo", "init failed", "missing", "not responding", ...)
    into status ok|warning|missing.
    - mark_cmd_ack/mark_cmd_failed: cmd:open s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
    [main.py, peripheral_status.py]
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2026-05-23 gate: confirm by evt:gate state, not cmd ack alone
    User flagged correctness: cmd ack only proves ESP32 parsed the JSON. It
    does NOT prove the servo moved or the LCD updated. Marking a gate
    "opened" or peripherals "ok" off the ack is dishonest reporting.
    1. GateTracker (link/gate_state.py):
    - threading.Lock replaced by threading.Condition.
    - update() now notify_all() on every state change.
    - New wait_for_state(target, timeout) blocks the caller until the
    state matches (or timeout). Case-insensitive target.
    - 7 unit tests for transitions + wait semantics.
    2. PeripheralTracker (link/peripheral_status.py):
    - mark_cmd_ack no longer infers servo+lcd "ok" from a succes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
    [gate_state.py, main.py, peripheral_status.py]
2026-05-23 peripherals: na status for SG90 servo + buzzer (no feedback)
    User confirmed accepting the limitation that SG90 hobby servos and
    passive buzzers physically can't be verified from the MCU because they
    have no feedback wire. Previous behaviour misleadingly marked them
    "ok" off the gate state transition. Honest report instead:
    - New status "na" (not applicable / no feedback available). Purple
    badge (#6f42c1) on the dashboard.
    - NO_FEEDBACK_PERIPHERALS = ("servo", "buzzer") — both initialized
    to "na" with explanatory message: "no feedback wire — verify by
    physical observation only (SG90/buzzer don't report back to MCU)".
    - update_from_log skips NO_FEEDBACK_PERIPHERALS so even if firmwa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
    [peripheral_status.py]
2026-05-23 two_factor: consumption cooldown — one check-in per visit
    User reported that while QR + face stay in frame, the daemon
    re-emitted CheckInEvent on every detector frame (10-15 fps),
    re-inserting face_encoding rows and re-firing cmd:open until the
    auth_cooldown_s gate downstream clamped them.
    Root cause: TwoFactorState consumed a pair, cleared both slots, but
    the very next detector frame refilled both slots with fresh data
    because the user hadn't moved → another pair → another CheckInEvent.
    Fix in three places:
    1. TwoFactorState gains `consumption_cooldown_s` (default 5s) and
    `_last_consumed_mono`. After _try_consume_locked returns a pair it
    stamps the consume time. Subsequent _t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
    [main.py]
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2026-06-12 fix(daemon): defensive try/except in _consume_bus
    Unhandled exceptions from DB writes (SD full, schema drift) were killing
    the bus-consumer thread silently — daemon stayed 'running' but processed
    no events. Now logs + emits a synthetic 'error internal' audit so the
    operator sees the failure on the dashboard, with 0.5 s back-off.
    [main.py]
2026-06-12 fix(daemon): clean shutdown on web port-in-use
    Previously OSError EADDRINUSE killed the Flask thread only; daemon kept
    running with web dead. Now triggers full shutdown so systemd restarts.
    [main.py]
2026-06-12 fix(firmware): LCD restore timer on RFID denial — fixes reported hang
    After a denied RFID scan the LCD was stuck on 'Access denied' forever
    because no code path scheduled a return to lcd_show_idle(). New one-shot
    2500 ms timer (g_lcd_restore_timer) posts EV_T_LCD_RESTORE; dispatcher
    calls lcd_show_idle() only if FSM is still in S_IDLE so we don't stomp
    an opening/closing message.
    [gate_fsm.cpp, main.cpp]
2026-06-12 chore(firmware): carry forward pre-session WIP notes + upload_speed flake fix
    - platformio.ini: upload_speed 921600 → 115200 (worked around CP210x flake)
    - uart_link.cpp: 8-line comment explaining why setRxBufferSize stays after begin()
    - lcd_drv.cpp: 7-line comment explaining the harmless [W] from Wire.begin
    Baseline so subsequent task commits in this branch only contain their
    intended changes. No functional behaviour change.
    [lcd_drv.cpp, uart_link.cpp]
2026-06-12 fix(firmware): non-blocking buzzer beeps — frees FSM task
    buzzer_beep_err() was blocking the FSM task for 360 ms (6 × 60 ms
    vTaskDelay). During the stall, the event queue wasn't drained, so rapid
    re-taps were silently dropped. Refactored into a FreeRTOS timer-driven
    state machine; FSM task returns immediately. Legacy blocking entries
    kept as wrappers so non-FSM callers compile unchanged.
    [buzzer_drv.cpp, gate_fsm.cpp]
2026-06-12 feat(firmware): LCD presence icons foundation — glyphs + accessors
    Adds the two custom HD44780 glyphs (obstacle warning at cell 0, RFID
    card at cell 1), lcd_update_icons() that writes only on state change to
    avoid I²C floods, and accessors sensor_is_obstacle() + rfid_is_card_present()
    (with a 300 ms hold so the RFID icon doesn't flicker between poll cycles).
    Row 0 text area shrunk to columns 0-13 to leave 14-15 for icons.
    [lcd_drv.cpp, rfid.cpp, sensor.cpp]
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
